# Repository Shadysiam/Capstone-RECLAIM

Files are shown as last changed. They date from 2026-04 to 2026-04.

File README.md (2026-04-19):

# RECLAIM — Autonomous Waste Collection & Sorting Robot

> **MSE 4499 Engineering Capstone — Western University, 2025–2026**
> **🏆 3rd Place at Capstone Showcase, March 26, 2026**

RECLAIM is an autonomous indoor robot designed to navigate post-event venues, detect waste on the ground using computer vision and depth sensing, pick it up with a 6-DOF robotic arm, classify it (recyclable / compost / landfill), and deposit it in the correct bin — fully autonomously.

---

## Demo

| | |
|---|---|
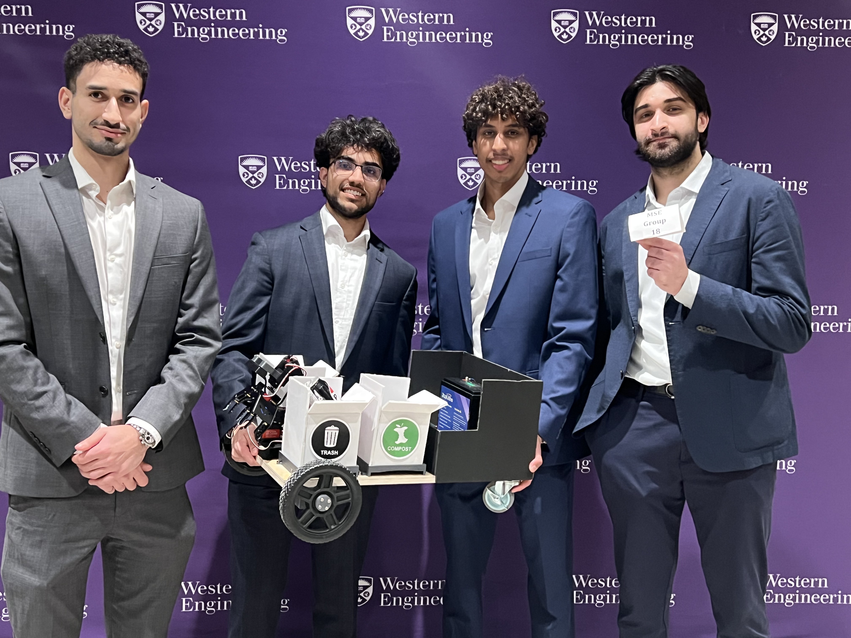
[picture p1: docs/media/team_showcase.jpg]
Team at Showcase
|  | **Western Engineering Capstone Showcase — March 26, 2026** <br><br> Team RECLAIM with the robot at the showcase. The arm, differential drive base, and sorting bins (Trash / Compost) are visible. <br><br> 🏆 **3rd Place overall** |

### Robot in Action

*Click any thumbnail to watch*

| | | |
|---|---|---|
| Demo 1 (https://youtube.com/shorts/9OcipLxrr-4) | Demo 2 (https://youtube.com/shorts/SzoJCjD1EAE) | Demo 3 (https://youtube.com/shorts/PJnd1PVIbLY) |

---

## System Overview

```
                          RECLAIM Robot

  ┌─────────────┐   ┌─────────────┐   ┌───────────────────────┐
  │ RPLIDAR A1  │   │  OAK-D Lite │   │   Jetson Orin NX      │
  │   LiDAR     │──▶│   Camera    │──▶│   MIC-711 / ROS2      │
  └─────────────┘   └─────────────┘   └───────────┬───────────┘
                                                   │
                                        ┌──────────▼──────────┐
                                        │     Teensy 4.1      │
                                        │     micro-ROS       │
                                        └──┬────────┬──────┬──┘
                                           │        │      │
             ┌─────────────────────────────┘        │      └─────────────────────┐
             │                                      │                            │
 ┌───────────▼──────────┐             ┌─────────────▼──────────┐  ┌─────────────▼──────────┐
 │  MD13C R3 (Left)     │             │   BTS7960 (Right)      │  │   6-DOF Servo Arm      │
 │  Motor Driver        │             │   Motor Driver         │  │   DS3218/DS3235/MG996R │
 └───────────┬──────────┘             └─────────────┬──────────┘  │   MoveIt2 Planning     │
             │                                      │             └────────────────────────┘
 ┌───────────▼──────────┐             ┌─────────────▼──────────┐
 │  JGB37-520 L Motor   │             │   JGB37-520 R Motor    │
 └──────────────────────┘             └────────────────────────┘
```

---

## Subsystems

### 🔋 Electrical & Power Distribution
- **Prototype:** 12.8V LiFePO4 battery → DC disconnect → 6-way fuse block → XINGYHENG buck converter (12V→6.8V servo bus) → Wago lever-nut distribution to 6 servo motors. 10,000µF bulk capacitance on servo rail.
- **Product PCB Design:** 24V input → dual-stage buck regulation (LM5116 24V→12V, TPS5430 12V→5V) → AMS1117 LDO (5V→3.3V) → E-stop relay circuit (G5LE-1A relay, IRLZ44N MOSFET gate driver, flyback diode protection) → fused distribution to all subsystems
- **KiCad Schematics:** Full hierarchical schematic design across 7 sheets (3 prototype + 4 product) with custom symbol libraries, netlist, and BOM documentation
- **Power Monitoring:** 3× INA226 current/power monitors on motor bus, compute rail, and servo rail

### 🚗 Locomotion & Motor Control
- **Differential drive** on two JGB37-520 12V motors with Hall-effect quadrature encoders
- **Mixed motor driver setup:** Cytron MD13C R3 (left) + BTS7960 (right), driven by Teensy 4.1 via PWM/DIR
- **PI velocity controller** on Teensy with per-wheel gains derived from step-response system identification
- Anti-windup, feedforward, low-pass filtering, ramp rate limiting (0.5 m/s²), static friction compensation
- **Calibrated odometry:** 1% distance error (50.5cm for 50cm target), 2-3° heading error on 360° spin
- Heading-hold controller in software bridge (Kp=2.0) to counteract castor drag

### 🗺️ Navigation & SLAM
- **SLAM Toolbox** for real-time mapping and localization using RPLIDAR A1M8
- **Nav2** autonomous navigation stack deployed on Jetson Orin NX via RoboStack/conda
- **`teensy_bridge.py`** ROS2 node: `/cmd_vel` → serial motor commands, encoder ticks → `/odom` publishing
- **Visual servoing pipeline** (`waste_tracker.py`): `SCAN → TURN_TO_TARGET → APPROACH → ALIGN` state machine
  - PID angular controller with Kalman filter (4-state: cx, cy, vx, vy) for smooth target tracking
  - EMA filtering, angular deadband, ramp limiting, coast-on-lost-detection
  - 5-frame detection confirmation before committing to a target
  - Speed proportional to distance: ramps from 0.12 to 0.04 m/s on approach

### 👁️ Perception
- **YOLOv8n** fine-tuned for waste classification (10-15 item classes → 3 bin categories)
- **OAK-D Lite** stereo depth camera via DepthAI v3 API — 640×480 @ 30.7 FPS
- Depth filtering (<1500mm), bbox area filtering (0.5–25% of frame), bottom-of-frame priority
- Detection published to `/perception/detections` as `DetectionArray` with 3D position

### 🦾 Robotic Arm
- 6-DOF arm with mixed servo types: DS3218 (270°, 21.5kg·cm), DS3235 (270°, 32kg·cm), MG996R
- LewanSoul mechanical claw gripper (0–193.5mm opening, 700g clamp force)
- Servo PWM controlled directly from Teensy 4.1 pins 10–15
- 6.8V servo bus with 10,000µF bulk capacitor to prevent brownout on simultaneous movement
- **MoveIt2** motion planning stack configured for the 6-DOF arm (`reclaim_arm_moveit_config`) — OMPL planner, joint limits, kinematics, and RViz visualization
- Full URDF model with STL meshes for each link — used for motion planning, collision checking, and Foxglove visualization

---

## Hardware

| Component | Model | Notes |
|---|---|---|
| Compute | Advantech MIC-711 (Jetson Orin NX) | ROS2 Humble via RoboStack/conda |
| Microcontroller | Teensy 4.1 | micro-ROS, USB serial @ 115200 baud |
| Camera | OAK-D Lite | DepthAI v3, USB 3.0, stereo depth |
| LiDAR | RPLIDAR A1M8 | 360°, 0.15–12m range |
| Drive Motors | 2× JGB37-520 12V 37RPM | Hall-effect quadrature encoders |
| Motor Drivers | Cytron MD13C R3 + BTS7960 | PWM+DIR / LPWM+RPWM |
| Arm Servos | DS3218, DS3235, MG996R | 6-DOF, mixed torque ratings |
| Battery | ZapLitho 12.8V 22Ah LiFePO4 | 30A BMS |
| Network | GL.iNet Mango router | WiFi bridge for SSH/rsync |

---

## Software Stack

| Layer | Technology |
|---|---|
| OS | Ubuntu 20.04 (JetPack 5.x) |
| Robot Framework | ROS2 Humble (via RoboStack/conda) |
| SLAM | SLAM Toolbox |
| Navigation | Nav2 |
| Firmware | PlatformIO / micro-ROS (Teensy 4.1) |
| Perception | YOLOv8n + DepthAI v3 |
| Visualization | Foxglove Studio |
| Schematic Design | KiCad 10 |

---

## Repository Structure

```
reclaim_ws/
├── src/
│   ├── reclaim_perception/       # OAK-D pipeline, YOLO inference, detection publisher
│   ├── reclaim_navigation/       # SLAM Toolbox, Nav2, LiDAR configs
│   ├── reclaim_control/          # Teensy firmware (PlatformIO) + micro-ROS
│   │   └── firmware/             # Motor control, encoder, servo firmware
│   ├── reclaim_bringup/          # State machine, system integration, top-level launch
│   └── reclaim_interfaces/       # Custom ROS2 msg/srv/action definitions
├── docs/
│   ├── product_pcb_electrical/   # Product KiCad schematic (4 sheets, STM32-based)
│   ├── prototype_pcb_electrical/ # Prototype KiCad schematic (3 sheets, Teensy-based)
│   ├── schematic_images/         # Exported PDFs + wiring guide
│   ├── Teensy.md                 # Pin map, flash procedure, serial comms
│   └── Perception_Strategy.md    # YOLO training strategy, OAK-D depth pipeline
├── matlab_sims/                  # Motor modelling, Bode plots, control tuning
├── sync.sh                       # rsync wrapper: edit locally → deploy to MIC-711
└── setup.sh                      # Environment setup script
```

---

## Quick Start (on MIC-711)

```bash
# Activate ROS2 environment
conda activate ros_env

# Sync from Mac (run on Mac)
./sync.sh reclaim_control --build

# Launch full system
source install/setup.bash
ros2 launch reclaim_bringup full_system.launch.py
```

---

## My Contributions (Shady Siam)

- **Electrical system design** — full power distribution for prototype and product PCB, including multi-stage buck regulation, E-stop relay circuit, servo bus design, and component selection
- **KiCad schematics** — 7-sheet hierarchical schematic design (product + prototype) with custom symbol libraries
- **Motor control firmware** — PI velocity controller on Teensy 4.1 with system identification, odometry calibration, and heading hold
- **ROS2 navigation stack** — SLAM Toolbox, Nav2, odometry bridge, visual servoing pipeline with Kalman-filtered target tracking
- **Systems integration** — full software environment setup on Jetson Orin NX, SSH/rsync workflow, Foxglove visualization

---

## Team

| Name | Role |
|---|---|
| Shady Siam | Electrical systems, power distribution, locomotion, navigation & SLAM |
| Issa Ahmed | AI stack, perception (YOLOv8n), autonomous operation |
| Dev Panara | Robotic arm, mechanical design, CAD |
| Abdul Kassem | Product locomotion (motor selection, torque analysis), commercialization strategy |

---

*Western University — MSE 4499 Engineering Capstone, 2025–2026*

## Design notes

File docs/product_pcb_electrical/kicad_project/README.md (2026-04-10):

# RECLAIM PCB — KiCad Project

## Files in This Directory

| File | Purpose |
|---|---|
| `RECLAIM_PCB/RECLAIM_PCB.kicad_pro` | KiCad project file (design rules, net classes, layer stack) |
| `RECLAIM_PCB/RECLAIM_PCB.kicad_sch` | Main schematic (all 9 sections, annotated) |
| `RECLAIM_PCB/fp-lib-table` | Footprint library table (maps to KiCad 7 standard libs) |
| `RECLAIM_PCB/sym-lib-table` | Symbol library table |
| `../bom.csv` | Complete BOM with MPN, footprint, value for every component |
| `../netlist.md` | Human-readable netlist — every pin-to-net connection |
| `../block_diagram.md` | System block diagrams (power + signal architecture) |
| `../component_justification.md` | Why each component was selected |

## How to Open in KiCad 7

1. Open KiCad 7 application
2. **File → Open Project** → select `RECLAIM_PCB/RECLAIM_PCB.kicad_pro`
3. In the KiCad project manager, open the schematic editor (`.kicad_sch`)

## How to Open in Flux (flux.ai)

1. Go to flux.ai → New Project
2. Import BOM: **File → Import → CSV BOM** → select `../bom.csv`
3. For the schematic, use `netlist.md` as a reference to draw connections

## Schematic Entry Order (recommended)

Start with the sections as they appear in `block_diagram.md`:

1. **Section 1 — Power Input & Distribution** ← START HERE
   - J_BATTERY, SW1, F1, K1, F2-F4
   - U1 (TPS5430 25V→12V), U2 (TPS5430 12V→5V), U3 (AMS1117 5V→3.3V)
   - Bulk caps C1-C4, decoupling C5-C8, buck inductors, freewheeling diodes

2. **Section 8 — E-Stop** ← Draw with Section 1 (shares relay K1)
   - Q1 (IRLZ44N), D2 (1N4007), R11 (1k gate resistor)
   - Bumper switch connectors J_BUMPER_FL/FR/RL/RR

3. **Section 2 — STM32F405 MCU**
   - U4 (STM32F405RGT6 LQFP-64)
   - Crystal Y1 + load caps C9/C10
   - Pull-up R1 (NRST), pull-down R2 (BOOT0)
   - SWD header J2, USB-C J3, CP2102N U_USB

4. **Section 3 — Motor Drivers**
   - U5L/U5R (DRV8243) × 2 identical sections
   - Sense resistors R3L/R3R, TVS diodes TVS1L/TVS1R
   - Motor output connectors J_MOTOR_L/R, encoder connectors J_ENC_L/R

5. **Section 4 — CAN Bus**
   - U6A/U6S (SN65HVD230) × 2
   - Termination R4A/R4S (120Ω)
   - CAN arm connector J_CAN_ARM

6. **Section 5 — IMU**
   - U7 (ICM-42688-P LGA-14)
   - Decoupling C15/C16

7. **Section 6 — Power Monitoring**
   - U8/U9/U10 (INA226) × 3
   - Shunt resistors R6/R7/R8 (10mΩ)
   - I2C address config via A0/A1 pins

8. **Section 7 — LED & Work Light**
   - WS2812B connector J_LED_STATUS, series R9, bulk C20
   - PT4115 U11, inductor L1, freewheeling D1, set resistor R10
   - Work light connector J_LED_WORK

## STM32F405 LQFP-64 Pin Assignment Quick Reference

Full table in `netlist.md`. Key assignments:
- PA2/PA3: USART2 TX/RX → Jetson micro-ROS
- PA5/6/7: SPI1 SCK/MISO/MOSI
- PA8/PA9: TIM1 encoder Left
- PB0/PB1/PB2: SPI CS for DRV_L, DRV_R, ICM
- PB4/PB5: TIM3 encoder Right
- PB6/PB7: I2C1 SCL/SDA → INA226×3
- PB8/PB9: CAN1 Arm bus
- PB12/PB13: CAN2 Spare
- PC6/PC7: TIM8 WS2812B / PT4115 PWM
- PC8: E-stop relay control
- PC9-PC12: Bumper switches

## Net Classes (already configured in .kicad_pro)

| Net Class | Track Width | Used For |
|---|---|---|
| Battery_Main | 6mm | VBAT, GND battery return |
| Power_25V_Motor | 4mm | VCC_25V, MOTOR_PWR_L/R |
| Power_5V_12V | 2mm | VCC_12V, VCC_5V |
| Default (3.3V + signal) | 0.25mm | VCC_3V3, all signals |
| CAN_Differential | 0.2mm | CAN_H/CAN_L pairs |

## PCB Layer Stack

```
Layer 1 (Top):     Signal + SMD components
Layer 2 (Inner 1): Ground plane — SOLID pour, no splits
Layer 3 (Inner 2): Power planes — split zones: 25V | 12V | 5V
Layer 4 (Bottom):  Signal + THT components + connectors
```

## DRC Rules Summary

- Min trace: 0.2mm signal / 2mm 5V-12V / 4mm 25V-motor / 6mm battery
- Min clearance: 0.2mm signal-to-signal / 0.5mm power-to-signal
- Via: 0.6mm drill / 1.0mm pad (signal) — 1.2mm drill / 2.0mm pad (power)
- Thermal relief: required on all power plane connections
- IMU: dedicated ground island, single via stitch
- Crystal: no traces underneath, ground guard ring
- CAN pairs: matched length to within 0.5mm, 120Ω differential impedance

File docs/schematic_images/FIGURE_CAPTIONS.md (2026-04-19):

# IEEE Figure Captions — Design Documentation

Copy-paste these into the report. Number sequentially within each section.

---

## Prototype Schematics

**Fig. X.** Prototype power distribution schematic. LiFePO4 12.8 V 22 Ah battery feeds a DPST DC switch, 6-way fuse block (30 A, 5 A, 5 A, 2 A), and XINGYHENG 20 A buck converter (6.8 V output) supplying servo bus via Wago 221-415 lever-nut connectors.
`Prototype_Power_Distribution.pdf`

**Fig. X.** Prototype Teensy 4.1 motor-control schematic. Cytron MD13C R3 (left motor) and BTS7960 (right motor) H-bridge drivers interface with Teensy 4.1 via PWM/DIR signals. Six servo PWM outputs (J1–J6) and two quadrature encoder inputs (left/right) are routed through net labels.
`Prototype_Teensy_Motor_Control.pdf`

**Fig. X.** Prototype peripheral and sensor connections. Advantech MIC-711 (Jetson Orin NX) connects via Ethernet (GL.iNet router), USB 3.0 (OAK-D Lite stereo camera), and USB 2.0 (RPLIDAR A1M8, Teensy 4.1).
`Prototype_Peripherals_Sensors.pdf`

---

## Product Schematics

**Fig. X.** Product power distribution and E-stop schematic. 25.6 V 100 Ah LiFePO4 battery, DC push-switch, fuse block (30 A main, 5 A, 2 A), relay-based E-stop circuit with flyback diode, LM51652 buck controller (12 V output), and post-regulation LDO (3.3 V). Total budget: 2,560 Wh.
`Product_Power_Distribution.pdf`

**Fig. X.** Product STM32F405RGT6 MCU schematic. 8 MHz crystal oscillator (C8/C10 load caps), SPI bus (SCK, MOSI, MISO) with chip-select lines for DRV8243 and IMU, dual CAN bus (CAN1/CAN2), USART2, I2C1 (4.7 k pull-ups), and quadrature encoder inputs (ENC_L_A/B, ENC_R_A/B).
`Product_STM32_MCU.pdf`

**Fig. X.** Product motor driver, CAN transceiver, and IMU schematic. Dual DRV8243-Q1 smart half-bridge gate drivers, CAN transceiver, 6-axis IMU, and associated decoupling capacitor network. Fault and enable lines routed to STM32 GPIO via net labels.
`Product_Drivers_CAN_IMU_Power.pdf`

**Fig. X.** Product connector, LED indicator, and USB schematic. Board-edge connectors for motors, encoders, servos, and external sensors. Status LEDs, USB Type-C connector for programming/debug, and UART debug header.
`Product_Connectors_LED_USB.pdf`

---

## Simulink / Control System Figures

**Fig. X.** Simulink block diagram of the prototype PI closed-loop velocity controller. The discrete-time loop operates at 50 Hz on the Teensy 4.1 with gains K_p = 940 and K_i = 38,230, PWM saturation (−255 to 255), and a first-order DC motor plant model (JGB37-520). Encoder feedback provides 7,560 ticks/rev odometry.
`Simulink_Prototype_Controls.png`

**Fig. X.** PI velocity controller step and ramp response. (Left) Step response at 0.20 m/s showing 52 ms rise time and 176 ms settling time for the closed-loop system versus open-loop PWM. (Center) Approach speed comparison at 0.12 m/s and 0.20 m/s setpoints. (Right) Ramp limiter effect at 0.3 m/s^2 limiting acceleration to prevent wheel slip.
`Simulink_Motor_Response_Prototype.jpg`

**Fig. X.** Closed-loop frequency response (Bode magnitude plot) of the PI-controlled drive system. The −3 dB bandwidth is 6.2 Hz, confirming adequate disturbance rejection for indoor navigation at speeds up to 0.20 m/s.
`Simulink_Bode_Plot.png`

---

## Notes

- Replace "Fig. X." with the actual figure number in context (e.g., Fig. 8.3.1).
- All schematics are vector PDFs — scale without quality loss.
- Simulink images are raster PNG/JPG — embed at native resolution.

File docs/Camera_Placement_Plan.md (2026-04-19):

# Camera Placement Plan — RECLAIM

> Decisions and specs for mounting the OAK-D Lite on the robot. Read this before designing the mount in CAD.

## Decision: Front Base Plate Mount (Eye-to-Hand)

Mount the OAK-D Lite on the front face of the arm base plate, below J1. The camera is fixed to the robot chassis (not the arm itself), so it does not move when the arm moves.

**Why eye-to-hand over eye-in-hand:**
- Simpler calibration (one static transform instead of a moving kinematic chain)
- Camera only needs a clear view before the arm moves
- Less wiring complexity, no cable routing through rotating joints

**Workflow:**
1. Robot drives toward waste, stops ~50cm away
2. Camera captures scene while arm is in home position (clear FOV)
3. YOLO detects waste, stereo depth gives 3D coordinates
4. Coordinates transformed from camera frame to arm base frame via static TF
5. Arm moves to pick. Camera view is occluded by the arm during pickup, but we already have the coordinates we need.

## Camera Selection

**OAK-D Lite, Auto-Focus version recommended.**

Reason: Objects will be at 30-50cm from the camera during pickup. Auto-focus handles close-range better. Fixed-focus is optimized for 50cm+ and vibrating platforms (not our use case).

## Depth Range Constraint

From Luxonis documentation (OAK-D Lite, 480P extended disparity):

| Range | Accuracy | Notes |
|---|---|---|
| 20-40cm | Works but >2% error | Absolute minimum depth range |
| **40cm - 3m** | **Sub-2% error** | **Ideal operating range** |
| >3m | Increasing error | Not relevant for pickup |

**This means the camera-to-waste distance should be >= 40cm for reliable depth.** Mounting low on the base plate may put objects at only ~30cm, which is below ideal. Two options:

### Option A: Low Mount (Base Plate)
- Camera at ~15cm above ground
- Object on ground at ~30cm from camera
- Marginal depth accuracy, but may be acceptable for pickup (we only need ~2cm precision for gripper alignment)
- Simplest mechanically

### Option B: Tower Mount (Behind Arm)
- Camera on a vertical post behind the arm, ~40cm above ground
- Tilted ~45 degrees downward
- Object on ground at ~47cm from camera (within ideal range)
- Better depth accuracy
- More complex mechanically, adds height to robot

**Current plan: Try Option A first.** Test depth accuracy at 30cm using `camera_detect.py`. If depth error is too large for reliable pickup, switch to Option B.

## OAK-D Lite Mounting Hardware

- **Back panel:** 2x M4 screw holes, 75mm VESA spacing (center-to-center)
- **Bottom:** 1x 1/4-20 UNC tripod mount
- **Camera dimensions:** ~91 x 28 x 17.5mm
- **Stereo baseline:** 7.5cm

For the base plate mount, the 1/4-20 tripod mount on the bottom is probably easiest. A simple L-bracket with a 1/4-20 bolt would work.

## Camera Intrinsics (for depth-to-3D conversion)

OAK-D Lite specs:
- RGB: 4208x3120, 81 DFOV
- Stereo: 640x480, 73 HFOV, 58 VFOV (per mono camera)
- Combined: ~69 HFOV, ~54 VFOV for depth

Exact intrinsics (fx, fy, cx, cy) are device-specific and read at runtime from the camera's EEPROM via DepthAI API.

## Static Transform: Camera to J1

This transform needs to be measured after the mount is built and the arm is assembled in CAD.

```
# Transform chain
map -> odom -> base_link -> camera_link -> camera_optical_frame

# The static TF we need to define:
base_link -> camera_link
```

**To measure:** Once the mount is CAD'd, extract the (x, y, z) offset and (roll, pitch, yaw) rotation from the camera optical center to the J1 rotation axis. This goes into a static transform publisher in the launch file.

## CAD Tasks

1. **Design camera mount bracket** — L-bracket or plate that attaches to arm base plate, holds OAK-D Lite via 1/4-20 bolt or M4 screws
2. **Model OAK-D Lite** — Use dimensions from Luxonis (91 x 28 x 17.5mm, 7.5cm baseline, mounting holes)
3. **Integrate into full arm assembly CAD** — Position camera mount on base plate, verify no collision with arm in home position and during pickup sequence
4. **Extract camera-to-J1 transform** — Measure offset from CAD for the static TF
5. **Verify FOV clearance** — Ensure the camera's 69x54 degree FOV covers the ground area in front of the robot at the expected pickup distance

## Open Questions

- Exact chassis height (depends on final frame design with 7" wheels)
- Whether 30cm depth accuracy is good enough (test empirically)
- Camera tilt angle (0 degrees = horizontal, need slight downward tilt to see ground)
- Cable routing from camera to MIC-711 (USB3 cable, max ~3m)

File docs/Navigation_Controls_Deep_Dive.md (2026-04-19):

# RECLAIM Navigation & Controls — Deep Dive

## How Every Constant Was Determined

### Wheel Radius: 0.05232m

**Method**: Iterative calibration. Command the robot to drive forward 50cm (using encoder counts). Measure actual distance with tape measure.

```
expected_distance = (ticks / 7560) * 2pi * r
```

If the robot drove 54.5cm when we expected 50cm, the radius is too big. Adjust:
```
r_new = r_old * (expected / actual) = 0.048 * (50 / 54.5) = 0.04404
```

Iterated 5 times until forward and reverse distance matched within ~1cm over 50cm. Final value: **0.05232m**.

### Wheel Separation: 0.470m

**Method**: 360 degree spin test. Command the robot to spin in place for exactly one full rotation (using encoder-based yaw). Measure the actual rotation.

```
yaw_per_tick = (2pi * wheel_radius) / (ticks_per_rev * wheel_separation)
```

If the robot overshot 360 by 18 degrees with wheel_sep = 0.494, the separation is too large:
```
sep_new = sep_old * (actual_rotation / expected_rotation) = 0.494 * (378 / 360) = 0.470
```

### Ticks Per Rev: 7560

**Method**: Hardware spec confirmed by measurement. JGB37-520 has:
- 7 PPR (pulses per revolution) base encoder
- 270:1 gearbox
- Quadrature decoding (x4)
```
7 * 270 * 4 = 7560 ticks per output shaft revolution
```

Verified by marking the wheel, spinning one full revolution by hand, and reading TICKS from serial.

### P Gain (Kp = 0.003 turn, 0.002 approach)

**Method**: Empirical tuning starting from theoretical estimate.

Relationship: `angular_velocity = Kp * pixel_offset`

Image is 640px wide, so max offset from center is 320px.

At Kp = 0.003: `max_w = 0.003 * 320 = 0.96 rad/s` (capped at 0.20)

Tuning logic:
- Too high -> oscillation (overshoots center, corrects back, overshoots again)
- Too low -> sluggish (takes many seconds to center, target might move)
- 0.003 produces 0.30 rad/s at 100px offset -- aggressive enough to center in ~1s
- 0.002 for approach because at 0.25 m/s forward speed, fast angular corrections cause visible swerving

### Motor Deadband: 0.04 rad/s

**Method**: Observation. Send decreasing angular velocities and watch when the motors stop responding. Below ~0.04 rad/s, the wheel speed commands translate to PWM values too low to overcome stiction in the motor + gearbox. Hardware limitation of the JGB37-520 with 270:1 reduction.

### EMA Alpha: 0.5

**Method**: Tradeoff analysis between responsiveness and smoothness.

```
alpha = 0.5:  50% raw, 50% previous   -> settles in ~3 frames (100ms)
alpha = 0.3:  30% raw, 70% previous   -> settles in ~6 frames (200ms)
alpha = 0.8:  80% raw, 20% previous   -> settles in ~1 frame (barely filters)
```

At 30fps, raw data has ~8px noise. Alpha 0.5 cuts noise in half without noticeable lag. 0.3 was too sluggish, 0.8 barely filtered.

### Heading Hold Kp: 2.0

**Method**: Straight-line driving test (2m).

- Kp = 1.0: corrects slowly, robot drifts ~5cm over 2m
- Kp = 2.0: snaps back within ~200ms, drift < 1cm over 2m
- Kp = 4.0: overcorrects, visible wobble

### Scan Speed: 0.3 rad/s

Full 360 takes `6.28 / 0.3 = ~21 seconds`. At 30fps, camera captures ~3 frames per degree of rotation.

### Approach Max Speed: 0.25 m/s

Motors' no-load speed is 37 RPM:
```
max_wheel_speed = 0.05232 * 2pi * 37/60 = 0.203 m/s
```

0.25 m/s is achievable during straight driving where both wheels share load.

### Stop Distance: 200mm (base_x)

Arm's working range: gripper reaches approximately 150-250mm from J1 base joint. 200mm puts the object in the middle of reachable zone.

### S-curve Ramp: 1.5 seconds

Cosine ramp has zero acceleration at start and end (no jerk):

```
v(t) = v_target * 0.5 * (1 - cos(pi * t / 1.5))
a(t) = v_target * pi/(2*1.5) * sin(pi * t / 1.5)
```

At t=0: a = 0 (no jerk). At t=0.75s: a = max. At t=1.5s: a = 0 (smooth).

### Max Acceleration: 0.3 m/s^2

Prevents wheel slip on smooth floors. Going from 0 to 0.20 m/s in one tick (33ms) would require 6 m/s^2 -- wheels slip on tile. At 0.3 m/s^2, takes ~0.67s.

### Confidence Threshold: 0.50

YOLO standard. 0.30 catches more but also picks up shadows/stains. 0.70 misses partially occluded objects.

### Confirm Threshold: 3 frames

At 20Hz, 3 frames = 150ms. Real objects persist for hundreds of frames. Noise rarely lasts >1-2 frames.

---

## The Full Control Hierarchy

### Layer 1: Teensy Firmware (Lowest Level)

Receives `SETVEL 0.108 0.132` over USB serial. Runs PI controller on each wheel:

```
error = target_velocity - measured_velocity
PWM += Kp * error + Ki * integral(error)
```

Measured velocity from encoders: 7560 ticks/rev, sampled at ~100Hz.
```
velocity = (ticks_per_sec / 7560) * 2pi * 0.05232
```

### Layer 2: Teensy Bridge (Middle Level)

ROS2 node on MIC-711. Four responsibilities:

**a) Velocity conversion** -- differential drive inverse kinematics:
```
v_left  = v - w * 0.235
v_right = v + w * 0.235
```

**b) Heading hold** -- locks heading when driving straight:
```python
if abs(v) > 0.005 and abs(w) < 0.02:
    heading_error = target_heading - actual_heading
    w = 2.0 * heading_error
```

**c) Ramp limiter** -- caps acceleration at 0.3 m/s^2

**d) Odometry** -- dead reckoning from encoder ticks at 10Hz:
```
delta_distance = (delta_left + delta_right) / 2
delta_theta    = (delta_right - delta_left) / 0.470
x += delta_distance * cos(theta)
y += delta_distance * sin(theta)
```

### Layer 3: Waste Tracker (Top Level -- The Brain)

State machine with visual servoing:

**SCAN**: Rotate at 0.3 rad/s. Confirm detections over 3 frames. Lock on nearest.

**TURN_TO_TARGET**: P controller centers target in camera frame.
```
pixel_offset = target_cx - 320
angular_vel = -0.003 * pixel_offset
```

**APPROACH**: Drive forward (speed proportional to distance) while steering to keep centered.
```
v = 0.04 + (0.25 - 0.04) * dist_ratio
w = -0.002 * pixel_offset
```

**ALIGN**: Final precise centering. 5 stable frames within 30px of center.

### The 4-Stage Smoothing Pipeline

```
Raw bbox -> Bbox EMA (alpha=0.5) -> P controller -> Angular EMA (alpha=0.45) -> Deadband taper -> Sinusoidal ramp -> cmd_vel
```

---

## Knowledge Test

### Phase 1: Fundamentals

1. Robot needs v=0.15 m/s, w=0.10 rad/s. What are left/right wheel velocities?
   **Answer**: v_left = 0.15 - 0.10*0.235 = 0.1265 m/s, v_right = 0.15 + 0.10*0.235 = 0.1735 m/s

2. Left encoder reads 3780 more ticks, right reads 3780. How far? Turn?
   **Answer**: Distance = (3780/7560) * 2pi * 0.05232 = 0.1645m. No turn -- both equal.

3. Target 80px right of center, Kp=0.003. Angular velocity? Direction?
   **Answer**: w = -0.003 * 80 = -0.24 rad/s. Turns right (clockwise, negative).

4. EMA alpha=0.5, current=0.10 rad/s, new raw=0.20 rad/s. New filtered?
   **Answer**: 0.5 * 0.20 + 0.5 * 0.10 = 0.15 rad/s

### Phase 2: State Machine Logic

5. SCAN: cup detected 2 frames, lost 1 frame, detected again. Lock on?
   **Answer**: No -- confirm resets on loss (no gap tolerance in friend's version).

6. APPROACH, cam_z=700mm. Forward speed? (before ramp)
   **Answer**: dist_ratio = (700-250)/1100 = 0.409. v = 0.04 + 0.21*0.409 = 0.126 m/s

7. APPROACH, target lost, cam_z was 400mm. What happens?
   **Answer**: Lost at close range (<500mm) for 50 frames -> IDLE. Probably at target.

8. TURN, detection 250px from last known. Returned by _find_target_in_detections?
   **Answer**: Yes -- during TURN, max_radius = 300px. 250 < 300.

### Phase 3: Smoothing & Controls

9. Why is Ki harmful if target disappears for 20 frames?
   **Answer**: Integral winds up during loss (error stays large). When target reappears, accumulated integral causes huge overshoot.

10. t=0.5s into approach (ramp_time=1.5s). Fraction of full speed?
    **Answer**: ramp = 0.5*(1-cos(pi*0.5/1.5)) = 0.5*(1-cos(60deg)) = 0.5*0.5 = 0.25 (25%)

11. P controller outputs 0.02 rad/s. What gets sent to motors?
    **Answer**: 0.02 < 0.04 deadband, overridden to 0.04 rad/s.

12. Driving straight at 0.12 m/s, heading drifts 0.05 rad. Heading hold output?
    **Answer**: w = 2.0 * 0.05 = 0.10 rad/s corrective rotation.

### Phase 4: System Integration

13. TRT server down for 3s during APPROACH?
    **Answer**: latest_detections stays empty. target_lost_count hits 50 (2.5s). Decides based on last depth.

14. Why Connection: close on HTTP requests?
    **Answer**: Prevents stale keep-alive state. Each request is fresh.

15. Tracker crashes but bridge keeps running?
    **Answer**: cmd_vel timeout fires after 0.5s. Motors stop safely.

16. Wheel radius wrong by 10% -- what breaks?
    **Answer**: Odometry position is off, but yaw uses ratio of left/right so mostly unaffected. Approach stop uses cam_z not odometry so still fine. Main break is distance estimation.

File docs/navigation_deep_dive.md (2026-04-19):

# RECLAIM — Navigation & Controls Deep Dive

## How Every Constant Was Determined

### Wheel Radius: 0.05232m

**How we got it**: Iterative calibration. Command the robot to drive forward 50cm (using encoder counts). Measure the actual distance with a tape measure.

```
expected_distance = (ticks / 7560) * 2pi * r
```

If the robot drove 54.5cm when we expected 50cm, the radius is too big. Adjust:
```
r_new = r_old * (expected / actual) = 0.048 * (50 / 54.5) = 0.04404
```

This was iterated 5 times until forward and reverse distance matched within ~1cm over 50cm. Final value: **0.05232m**.

### Wheel Separation: 0.470m

**How we got it**: 360 spin test. Command the robot to spin in place for exactly one full rotation (using encoder-based yaw). Measure the actual rotation.

```
yaw_per_tick = (2pi * wheel_radius) / (ticks_per_rev * wheel_separation)
```

If the robot overshot 360 by 18 degrees with `wheel_sep = 0.494`, the separation is too large. The wheels are closer than we thought, so each tick produces more rotation than expected:
```
sep_new = sep_old * (actual_rotation / expected_rotation) = 0.494 * (378 / 360) = 0.470
```

### Ticks Per Rev: 7560

**How we got it**: Hardware spec confirmed by measurement. The JGB37-520 has:
- 7 PPR (pulses per revolution) base encoder
- 270:1 gearbox
- Quadrature decoding (x4)
```
7 * 270 * 4 = 7560 ticks per output shaft revolution
```

Verified by marking the wheel, spinning one full revolution by hand, and reading TICKS from serial.

### P Gain (Kp = 0.003 turn, 0.002 approach)

**How it was tuned**: Start with a guess, then adjust empirically.

The relationship is: `angular_velocity = Kp * pixel_offset`

Image is 640px wide, so max offset from center is 320px.

At Kp = 0.003: `max_w = 0.003 * 320 = 0.96 rad/s` (capped at 0.20)

The thought process:
- Too high: oscillation (overshoots center, corrects back, overshoots again)
- Too low: sluggish (takes many seconds to center, target might move)
- 0.003 produces 0.30 rad/s at 100px offset — aggressive enough to center in ~1s
- 0.002 for approach because at 0.25 m/s forward speed, fast angular corrections cause visible swerving

### Motor Deadband: 0.04 rad/s

**How we got it**: Observation. Send decreasing angular velocities and watch when the motors stop responding. Below ~0.04 rad/s, the wheel speed commands translate to PWM values too low to overcome stiction in the motor + gearbox. This is a **hardware limitation** of the JGB37-520 with 270:1 reduction — the gearbox has high stiction at low speeds.

### EMA Alpha: 0.5

**How we chose it**: Tradeoff between responsiveness and smoothness.

```
alpha = 0.5:  50% raw, 50% previous   -> settles in ~3 frames (100ms)
alpha = 0.3:  30% raw, 70% previous   -> settles in ~6 frames (200ms)
alpha = 0.8:  80% raw, 20% previous   -> settles in ~1 frame (barely filters)
```

At 30fps, the raw data is already fairly clean (~8px noise). Alpha 0.5 cuts the noise in half without adding noticeable lag. Chosen by testing — 0.3 was too sluggish (robot couldn't track a moving target), 0.8 was barely different from raw.

### Heading Hold Kp: 2.0

**How it was tuned**: Drive the robot straight for 2m. Watch if it drifts.

- Kp = 1.0: corrects slowly, robot drifts ~5cm over 2m
- Kp = 2.0: snaps back within ~200ms, drift < 1cm over 2m
- Kp = 4.0: overcorrects, visible wobble

2.0 is the sweet spot — strong enough to counteract castor drag immediately, not so strong it oscillates.

### Scan Speed: 0.3 rad/s

**How it was chosen**: Full 360 takes `6.28 / 0.3 = ~21 seconds`. This gives the camera enough time to see objects at each angle — at 30fps, the camera captures ~3 frames per degree of rotation. Too fast and you miss objects. Too slow and the scan takes forever.

### Approach Max Speed: 0.25 m/s

**Why this value**: The motors' no-load speed is 37 RPM:
```
max_wheel_speed = 0.05232 * 2pi * 37/60 = 0.203 m/s
```

At 0.25 m/s, one wheel (during a turn) would need to go faster than this — so the actual achievable straight-line speed is slightly above 0.20. 0.25 is aggressive but achievable because during straight driving both wheels share the load.

### Stop Distance: 200mm (base_x)

**Why**: This is the arm's working range. The gripper can reach approximately 150-250mm from the J1 base joint. Stopping at 200mm puts the object right in the middle of the arm's reachable zone. This is measured from the camera-to-base_link transform, not raw camera depth.

### S-curve Ramp: 1.5 seconds

**Why cosine, why 1.5s**:

Linear ramp (v increases at constant rate) has **discontinuous acceleration** — at t=0 acceleration jumps from 0 to some value, causing a jerk. Cosine ramp has **zero acceleration at start and end**:

```
v(t) = v_target * 0.5 * (1 - cos(pi * t / 1.5))
a(t) = v_target * pi/(2*1.5) * sin(pi * t / 1.5)
```

At t=0: `a = 0` (no jerk). At t=0.75s: `a = max` (peak acceleration). At t=1.5s: `a = 0` (smooth arrival at target speed).

1.5s was chosen to balance smoothness vs responsiveness. At 0.20 m/s, 1.5s means the robot covers ~15cm during ramp-up. Too long and the robot seems sluggish. Too short and you still get a jolt.

### Max Acceleration: 0.3 m/s^2

**Why**: At the bridge level, this prevents wheel slip on smooth floors. Going from 0 to 0.20 m/s in one tick (33ms) would require 6 m/s^2 — the wheels would slip on tile/laminate floors. At 0.3 m/s^2, it takes ~0.67s to reach full speed — smooth and grippy.

### Confidence Threshold: 0.50

**Why**: YOLO outputs a confidence score 0-1. At 0.50, roughly half of real trash is detected with very few false positives. Lower (0.30) catches more trash but also picks up floor stains, shadows. Higher (0.70) misses partially occluded objects. 0.50 is the standard YOLO threshold.

### Confirm Threshold: 3 frames

**Why**: At 20Hz polling, 3 frames = 150ms. A real object will persist for hundreds of frames. Noise/reflections rarely last more than 1-2 frames. 3 is the minimum that reliably filters flicker without adding noticeable delay (you don't want the robot to rotate past the object waiting for confirmation).

---

## The Full System Architecture

### The Physical System

Differential drive robot — two powered wheels with encoders, two passive castors. The left and right motors are independently controlled:

- **Both wheels same speed** -> drives straight
- **Right faster than left** -> arcs left
- **Wheels opposite directions** -> spins in place

The fundamental equation (inverse kinematics):
```
v_left  = v - w * 0.235
v_right = v + w * 0.235
```

The `0.235` is half the wheel separation (0.470m / 2).

### The Control Hierarchy (Bottom to Top)

```
Layer 3:  WHAT to do     waste_tracker_trt.py    "see trash, drive to it"
Layer 2:  HOW to move    teensy_bridge.py        "v=0.12, w=0.05 -> left/right wheel speeds"
Layer 1:  MAKE it move   Teensy firmware          "target velocity -> PWM via PI loop"
```

#### Layer 1: Teensy (Lowest Level)

The Teensy receives `SETVEL 0.108 0.132` over USB serial. It runs a **PI controller** on each wheel:

```
error = target_velocity - measured_velocity
PWM += Kp * error + Ki * integral(error)
```

The measured velocity comes from the encoders. 7560 ticks per wheel revolution, sampled at ~100Hz on the Teensy. It converts ticks/sec to m/s using:

```
velocity = (ticks_per_sec / 7560) * 2pi * 0.05232
```

This is a **closed-loop velocity controller** — it adjusts PWM to match the target speed regardless of battery voltage, floor friction, or load.

#### Layer 2: Teensy Bridge (Middle Level)

ROS2 node on the MIC-711. Does three things:

**a) Velocity conversion** — takes `/cmd_vel` (Twist message with v and w) and converts to left/right wheel velocities using the diff drive equation.

**b) Heading hold** — when the tracker says "drive straight" (`w ~ 0`), the bridge:
1. Records the current heading from odometry
2. Every tick, measures the actual heading
3. If the robot drifts, computes: `w_correction = 2.0 * (target_heading - actual_heading)`
4. Adds this correction to the wheel commands

Even though the tracker says "go straight," the bridge actively fights castor drift.

**c) Odometry** — polls encoder ticks at 10Hz, computes position:
```
delta_left  = (delta_ticks_L / 7560) * 2pi * 0.05232   # meters left wheel
delta_right = (delta_ticks_R / 7560) * 2pi * 0.05232   # meters right wheel
delta_distance = (delta_left + delta_right) / 2          # center displacement
delta_theta    = (delta_right - delta_left) / 0.470      # heading change
x += delta_distance * cos(theta)
y += delta_distance * sin(theta)
theta += delta_theta
```

This is **dead reckoning** — accumulates position from wheel movements. Drifts over time but accurate enough for scan completion and heading hold.

**d) Ramp limiter** — caps acceleration at 0.3 m/s^2. Prevents jerky starts.

#### Layer 3: Waste Tracker (Top Level — The Brain)

Finite state machine with visual servoing.

---

## The State Machine In Detail

### State 1: SCAN

**Purpose**: Find waste on the ground by rotating in place.

**How it works**:
1. Commands `w = 0.3 rad/s` (CCW rotation, ~21 seconds for 360 degrees)
2. Every tick, reads yaw from odometry to track rotation progress
3. TRT poll thread gets detections in parallel
4. Each tick checks: "did I see anything?"

**Scan accumulation hack**: Castors scrub during rotation causing brief backward yaw jumps. Reverse yaw counted at 30% to prevent premature "360 complete".

**Detection confirmation**: Requires 3 consistent frames — same class, cx within 80px, depth within 500mm. During confirmation, scan slows to 40%.

If full 360 with no lock: picks nearest from scan list.

### State 2: TURN_TO_TARGET

**Purpose**: Rotate to center the target in the camera frame.

**Core equation**:
```
pixel_offset = target_cx - 320
angular_vel = -0.003 * pixel_offset
```

100px right of center -> w = -0.30 rad/s (turn right)
50px left of center  -> w = +0.15 rad/s (turn left)

Negative sign: camera x-axis is opposite to rotation direction.

**Motor deadband override**: If |w| < 0.04, force to 0.04. Motors physically can't spin slower.

**EMA smoothing**: `w = 0.5 * raw + 0.5 * previous`. Filters bbox jitter.

**Transition**: |pixel_offset| < 50px -> APPROACH.

**When lost**: Coasts at last angular velocity. After 50 frames -> rescan.

### State 3: APPROACH

**Purpose**: Drive toward target while keeping it centered.

**Speed control**:
```
dist_ratio = (cam_z - 250) / 1100     # normalized 0 to 1
v = 0.04 + (0.25 - 0.04) * dist_ratio
```
At 1350mm: v = 0.25 m/s (full). At 800mm: v = 0.145. At 250mm: v = 0.04 (minimum).

**Softer steering**: Kp = 0.002 (not 0.003). Less swerving at speed.

**S-curve startup ramp**:
```
ramp = 0.5 * (1 - cos(pi * elapsed / 1.5))
v *= ramp
w *= ramp
```
Zero jerk at start and end. Both linear and angular ramped.

**Dual stop condition**:
- Primary: `base_x <= 200mm` (from camera-to-base_link transform)
- Fallback: `cam_z <= 250mm`

**When lost**: Coast forward at 0.04 m/s. If lost too long at close range -> stop (probably at target).

### State 4: ALIGN

**Purpose**: Final precise centering before arm pickup.

Same P controller as TURN (Kp = 0.003, deadband override), but:
- Must be centered within 30px
- If base_x > 250mm, creep forward at 0.04 m/s
- Need 5 stable frames before declaring done

When done: publishes to `/pickup_request` for arm.

---

## The Detection Pipeline

### TRT Poll Thread (20Hz background)

```
HTTP GET /detection -> JSON parse -> confidence check -> spatial filter -> store
```

### Filtering

| Filter | Scan | Tracking | Why |
|---|---|---|-----|
| Max depth | 2500mm | 3000mm | Don't chase far objects during scan |
| Min cy (top of image) | 25% | 20% | Top of frame = not on floor |
| Max bbox area | 15% | 25% | Large = walls, people |
| Min bbox area | 0.3% | 0.3% | Tiny = noise |

### Target Matching (_find_target_in_detections)

Three-tier fallback:
1. **Position match**: Detection within 80px (150px during TURN) of last known position
2. **Class match**: Same class name, closest to last position
3. **Any nearby**: Any detection within 200-300px radius

---

## Showcase Talking Points

### 30-second version:
"The robot scans by rotating in place. When the camera detects waste confirmed over 3 frames, it locks on and uses a P controller to center the object in the camera frame. Then it drives toward it with distance-proportional speed and smooth cosine acceleration. A softer controller gain during approach prevents swerving. The teensy bridge converts the velocity commands to differential wheel speeds and adds heading hold to fight castor drift. The whole system runs at 20-30Hz."

### If they ask about smoothing:
"At 30 FPS, the raw bbox center has about 8 pixels of noise. We apply an EMA filter with alpha 0.5 to cut that in half, then cap the angular velocity and enforce a motor deadband of 0.04 rad/s — below that, the motors physically can't spin. The teensy bridge adds another layer with a 0.3 m/s^2 acceleration limit."

### If they ask about the P controller:
"We use two P gains — 0.003 during turning for aggressive centering, and 0.002 during approach to reduce swerving. The output is angular velocity in rad/s, proportional to how many pixels the target is off-center. 100 pixels off-center produces 0.3 rad/s of rotation."

### If they ask why not PID:
"At 30 FPS, the measurements are clean enough that integral and derivative terms add more problems than they solve. The integral causes windup when the target is temporarily lost, and the derivative amplifies noise. Pure P with EMA smoothing is sufficient."

---

## Learning Plan

### Phase 1: Fundamentals (30 min)

**Topics:**
1. Differential drive kinematics — v, w -> left/right wheel speeds
2. Dead reckoning odometry — ticks -> position
3. P controller — error * gain = output
4. EMA filter — what alpha does, responsiveness vs smoothness tradeoff

**Questions:**
1. The robot needs to drive at 0.15 m/s while turning left at 0.10 rad/s. What are the left and right wheel velocities?
2. The left encoder reads 3780 more ticks than last reading, right reads 3780. How far did the robot move? Did it turn?
3. The target is 80px to the right of center. With Kp = 0.003, what angular velocity is commanded? Which direction?
4. Your EMA has alpha = 0.5, current filtered value is 0.10 rad/s, new raw value is 0.20 rad/s. What's the new filtered value?

### Phase 2: State Machine Logic (30 min)

**Topics:**
1. State transitions — triggers
2. SCAN confirmation — why 3 frames, resets
3. APPROACH speed profile — distance to speed mapping
4. Target matching — 3-tier fallback
5. Lost target handling — coast vs rescan vs stop

**Questions:**
5. During SCAN, the robot detects a cup at 1500mm for 2 frames, loses it for 1 frame, then sees it again. Does it lock on?
6. In APPROACH, cam_z reads 700mm. What forward speed is commanded (before ramp)?
7. The robot is in APPROACH and loses the target. cam_z was 400mm. What happens?
8. During TURN, a detection is 250px from last known position. Does _find_target_in_detections return it?

### Phase 3: Smoothing & Controls (30 min)

**Topics:**
1. Why P-only (not PID) at 30fps
2. S-curve ramp math — cosine profile, zero jerk
3. Motor deadband — physical cause and software fix
4. Heading hold — fighting castor drift
5. Two-Kp strategy — softer gain during approach

**Questions:**
9. Why would Ki be harmful if the target disappears for 20 frames then comes back?
10. At t = 0.5s into approach (ramp_time = 1.5s), what fraction of full speed is the robot at?
11. P controller outputs 0.02 rad/s. What actually gets sent to motors?
12. Robot drives straight at 0.12 m/s, heading drifts 0.05 rad. What does heading hold produce?

### Phase 4: System Integration (20 min)

**Topics:**
1. Thread safety — camera_lock, two threads
2. TRT communication — HTTP polling, stale detection, DEPTH_MAX_MM
3. ROS2 topic flow — /cmd_vel, /odom, /robot_state, /pickup_request
4. Calibration chain — how constants feed into each other

**Questions:**
13. What happens if the TRT server goes down for 3 seconds during APPROACH?
14. Why does the poll thread use `Connection: close` on HTTP requests?
15. The cmd_vel timeout is 0.5s. What if the tracker crashes but bridge keeps running?
16. If wheel_radius is wrong by 10%, which behaviors break?

---

## Answers

1. `v_left = 0.15 - 0.10 * 0.235 = 0.1265 m/s`, `v_right = 0.15 + 0.10 * 0.235 = 0.1735 m/s`
2. Distance = `(3780/7560) * 2pi * 0.05232 = 0.1645m`. No turn — both wheels moved equally.
3. `w = -0.003 * 80 = -0.24 rad/s`. Turns right (clockwise).
4. `0.5 * 0.20 + 0.5 * 0.10 = 0.15 rad/s`
5. No — confirm count reaches 2, then resets to 0 when detection disappears (no gap tolerance in this version).
6. `dist_ratio = (700-250)/1100 = 0.409`. `v = 0.04 + 0.21 * 0.409 = 0.126 m/s`
7. Lost at close range (<500mm) for 50 frames -> `drive_only_done = True`, goes IDLE. Probably already at target.
8. During TURN, max_radius = 300px. 250 < 300. Yes, returns it.
9. While target is gone, pixel error stays large, integral winds up. When target reappears, accumulated integral causes huge overshoot — robot spins way past center.
10. `ramp = 0.5 * (1 - cos(pi * 0.5/1.5)) = 0.5 * (1 - cos(60deg)) = 0.5 * 0.5 = 0.25`. 25% speed.
11. 0.02 < 0.04 (deadband), overridden to 0.04 rad/s in the error direction. Without this, motors wouldn't move.
12. `w = 2.0 * 0.05 = 0.10 rad/s` corrective rotation.
13. Poll returns URLError, consecutive_errors increments. latest_detections stays empty. target_lost_count increments. After 50 frames (2.5s), decides based on last depth.
14. Prevents HTTP keep-alive accumulating stale state. Each request is fresh.
15. cmd_vel_timeout fires after 0.5s of no messages. Sends SETVEL 0.0 0.0. Motors stop safely.
16. Odometry position is wrong (thinks it moved more/less). BUT: scan yaw uses left/right ratio (unaffected by radius). Approach stop uses cam_z (unaffected). Heading hold uses yaw (unaffected). Main break: if other nodes rely on /odom position.

---

## Known Issue: DEPTH_MAX_MM = 600

The TRT server (`camera_detect_trt.py`) only reports detections within 600mm. This limits driving — the tracker can't see targets until very close. Needs to be changed to 3000mm for driving range. Will change later.

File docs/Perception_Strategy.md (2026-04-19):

# Perception Strategy — RECLAIM

> This doc captures all research, decisions, and implementation details for the perception pipeline. Every perception-related agent should read this before writing code.

## Problem Statement

First training attempt (Approach 1) failed badly:
- Recyclable AP50 = 0.45
- Compost AP50 = 0.00
- Landfill AP50 = 0.02

**Root cause: data imbalance, NOT model architecture.** TACO has almost no compost images, and Flickr download links are broken. The 3-class broad taxonomy (recyclable/compost/landfill) is also visually incoherent. "Recyclable" covers glass bottles, aluminum cans, and cardboard, which share no visual features.

## Key Decision: Fine-Grained Classes Mapped to Bins

**Train on 10-15 specific item classes, then map to bins via a lookup table.** This is strongly supported by the literature and gives three advantages:
1. Better per-class accuracy from visually coherent classes
2. Flexibility to change bin assignments without retraining
3. More interpretable results for demo

```python
BIN_MAP = {
    # Recyclable bin
    'plastic_bottle': 'recyclable', 'aluminum_can': 'recyclable',
    'glass_bottle': 'recyclable', 'cardboard': 'recyclable',
    'paper': 'recyclable', 'metal_lid': 'recyclable',
    # Compost bin
    'banana_peel': 'compost', 'food_waste': 'compost',
    'napkin': 'compost', 'paper_cup': 'compost',
    # Landfill bin
    'chip_bag': 'landfill', 'wrapper': 'landfill',
    'styrofoam': 'landfill', 'plastic_bag': 'landfill',
    'cigarette': 'landfill',
}
```

This taxonomy can be adjusted based on what datasets are available. The exact classes matter less than having visually distinct, balanced classes.

## Datasets to Use

| Dataset | Images | Classes | Why |
|---|---|---|-----|
| **detect-waste (merged)** | 28,000+ | 7 unified | Best merged corpus, includes TACO + 6 others. `github.com/wimlds-trojmiasto/detect-waste` |
| **GARBAGE CLASSIFICATION 3 (Roboflow)** | 10,000+ | 7 material types | `universe.roboflow.com/material-identification/garbage-classification-3` |
| **Drinking Waste** | 9,640 | 4 beverage containers | Good for recyclable bottles/cans. `kaggle.com/datasets/arkadiyhacks/drinking-waste-classification` |
| **RealWaste** | 4,752 | 9 classes inc. food organics | Critical for compost class. `archive.ics.uci.edu/dataset/908/realwaste` |
| **ZeroWaste (CVPR 2022)** | 4,503 | 4 recyclable types | `github.com/dbash/zerowaste` |

**For merging datasets:** Use FiftyOne (`pip install fiftyone`) for format conversion and dataset merging.

**Minimum target: 300 images per class.** Duplicate/augment minority classes to reach this.

## Training Configuration (YOLOv8n)

```python
from ultralytics import YOLO
model = YOLO("yolov8n.pt")  # COCO pretrained
model.train(
    data="waste.yaml",
    epochs=100,
    imgsz=640,
    fl_gamma=1.5,          # Enable focal loss (default 0.0 = disabled)
    image_weights=True,     # Sample images by class frequency
    copy_paste=0.3,         # Paste minority instances into other images
    mosaic=1.0,             # Combines 4 images — increases minority exposure
    mixup=0.15,             # Blend images together
    optimizer='AdamW',      # Better than SGD for small datasets
    lr0=0.001,              # Lower LR for fine-tuning
    freeze=10,              # Freeze backbone for first pass (30 epochs), then unfreeze
    patience=50,            # Early stopping
)
```

**Key augmentation**: `copy_paste=0.3` is the single most impactful technique for long-tail class distributions (CVPR 2021, Ghiasi et al.).

**Offline augmentation for minority classes** (3-5x copies using Albumentations):
```python
import albumentations as A
transform = A.Compose([
    A.RandomBrightnessContrast(p=0.5),
    A.GaussNoise(p=0.3),
    A.MotionBlur(blur_limit=7, p=0.3),
    A.RandomShadow(p=0.3),
    A.CLAHE(p=0.3),
], bbox_params=A.BboxParams(format='yolo'))
```

**Target accuracy: mAP50 >= 0.70.** Published results show 0.70-0.85 is achievable with balanced data on YOLOv8n.

## Fallback: Two-Stage Pipeline

If single-stage YOLO underperforms after fixing data:
1. Train YOLOv8 as binary "waste" vs "background" detector (high recall)
2. Crop detected regions
3. Classify crops with MobileNetV2 trained on balanced image-level datasets
4. This approach achieved 97.8% classification accuracy (Edge Impulse) and 70% AP + 75% classification (detect-waste project)

## OAK-D Lite Depth Pipeline

### SpatialDetectionNetwork (Recommended)

The OAK-D Lite can run YOLO + stereo depth on-device, outputting (X, Y, Z) in millimeters for every detection. This is the recommended approach.

**On-device performance:**
- YOLOv8n @ 416x416: ~31 FPS on Myriad X
- YOLOv8n @ 640x640: ~14 FPS on Myriad X

**Depth accuracy:** <2% error within 3m (±2cm at 1m, ±4cm at 2m). Min depth ~35cm standard, ~20cm with extended disparity. Sufficient for pickup at 0.5-2.0m.

**To use SpatialDetectionNetwork, the model must be converted to .blob format:**
```bash
# Export to ONNX
yolo export model=best.pt format=onnx imgsz=416 simplify=True opset=12

# Convert to blob via blobconverter
pip install blobconverter
```
```python
import blobconverter
blob_path = blobconverter.from_onnx(
    model="best.onnx",
    data_type="FP16",
    shaves=6,
    optimizer_params=["--mean_values=[0,0,0]", "--scale_values=[255,255,255]"]
)
```

Or use Luxonis online tool: `tools.luxonis.com`

**Critical: Use ONNX opset 12 and OpenVINO 2021.4** for best Myriad X compatibility.

### Alternative: YOLO on Jetson GPU + Depth from OAK-D

If SpatialDetectionNetwork doesn't work (e.g., blob conversion fails):
- Stream RGB + depth from OAK-D to Jetson
- Run YOLO on Jetson GPU with TensorRT (~52-66 FPS at 640x640)
- Sample depth at bounding box center
- Convert pixel (cx, cy, z_mm) to 3D using camera intrinsics

This adds complexity (manual depth sampling, RGB-depth alignment) but gives more flexibility with model choice.

### Jetson TensorRT Benchmarks (Orin NX)

| Model | Precision | Resolution | FPS | mAP50 (COCO) |
|---|---|---|-----|---|
| YOLOv8n | FP16 | 640x640 | ~52 | 52.5 |
| YOLOv8n | INT8 | 640x640 | ~66 | ~51.5 |
| YOLOv8s | FP16 | 640x640 | ~35 | 61.8 |

Export for TensorRT:
```python
model = YOLO("best.pt")
model.export(format="engine", imgsz=640, half=True, int8=True, device=0)
```

## YOLO26 Status: DO NOT USE YET

YOLO26n is ~3 mAP points better than YOLOv8n but:
- **Myriad X .blob compatibility is UNVERIFIED** as of March 2026
- Luxonis tools.luxonis.com does not list YOLO26 support
- NMS-free output tensor format may break DepthAI's YOLO parser
- The 3 mAP gain is negligible compared to 20-30 point gain from data fixes

**Decision: Stick with YOLOv8n for the demo.** Only switch if someone verifies blob conversion works.

## DepthAI v3 API Reminders

DepthAI 3.3.0 is installed. The v3 API is different from v2. See CLAUDE.md for the full v2→v3 migration reference.

**NOTE:** The SpatialDetectionNetwork code examples in the research doc use v2 API patterns (ColorCamera, XLinkOut, setBoardSocket, etc.). These WILL NOT WORK with DepthAI v3. When implementing SpatialDetectionNetwork, check DepthAI v3 docs at `docs.luxonis.com/software-v3/depthai/` for the correct v3 equivalents. The concepts are the same but the method names changed.

## Coordinate Transform: Camera → Robot

Transform chain: `map → odom → base_link → camera_link → camera_optical_frame`

- `map → odom`: from SLAM Toolbox / AMCL
- `odom → base_link`: from wheel odometry (Teensy encoders)
- `base_link → camera_link`: static transform (camera mount position)
- `camera_link → camera_optical_frame`: automatic from depthai-ros URDF

```python
import tf2_ros
from geometry_msgs.msg import PointStamped

tf_buffer = tf2_ros.Buffer()
tf_listener = tf2_ros.TransformListener(tf_buffer, node)

# Transform detection from camera frame to map frame
point = PointStamped()
point.header.frame_id = 'oak_rgb_camera_optical_frame'
point.point.x, point.point.y, point.point.z = x_cam, y_cam, z_cam
map_point = tf_buffer.transform(point, 'map', timeout=Duration(seconds=1.0))
```

## Navigation to Waste

Use `nav2_simple_commander` to navigate to 0.5m from detected waste, then visual servo for final alignment using YOLO bounding box centering via `/cmd_vel`.

## Arm Pickup Strategy

**UPDATE (March 2026): Pursuing MoveIt2 for IK-based picking.**

The original plan was to skip MoveIt2 and use pre-defined joint poses only. We're now pursuing MoveIt2 so the arm can compute inverse kinematics to reach arbitrary 3D positions detected by the camera. The pre-defined pose sequences (PICKUP command in firmware) remain as a fallback.

**Full pipeline:**
1. Camera detects waste via YOLO, stereo depth gives 3D position in camera frame
2. tf2 transforms coordinates from camera frame to arm base frame (static transform)
3. MoveIt2 computes IK solution for the target position
4. ros2_control hardware interface sends joint commands to Teensy via serial
5. Gripper closes (angle determined by object class or bounding box width)
6. Arm lifts and moves to appropriate bin using pre-defined bin poses

**Fallback (if MoveIt2 timeline slips):** Use pre-defined pose sequences with the PICKUP firmware command. Robot drives to ~30cm from waste, arm executes fixed pick sequence. Less precise but already working.

See `Camera_Placement_Plan.md` for camera mounting details and the camera-to-arm transform.

## Reference Repos

| Repo | Why it's useful |
|---|---|
| **MARIO-COM** (`github.com/bharadwaj-chukkala/MARIO-COM`) | Closest match: ROS2 + TurtleBot3 + Nav2 + arm pickup |
| **detect-waste** (`github.com/wimlds-trojmiasto/detect-waste`) | Best merged dataset + training scripts |
| **RoboSort** (`github.com/qppd/robo-sort`) | YOLO + LIDAR + 6DOF arm, serial protocol |
| **Trash Sorting Robot** (`github.com/bandofpv/Trash-Sorting-Robot`) | SSD + RPi + Dobot Arm, full BOM |
| **WasteGAN** (`github.com/bach05/wastegan`) | Synthetic data for rare waste classes (+30% minority improvement) |
| **Waste Detection YOLOv8** (`github.com/boss4848/waste-detection`) | YOLOv8 + Streamlit + Colab notebook |

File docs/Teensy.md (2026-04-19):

# Teensy 4.1 — RECLAIM Reference

## Connection

- **USB Device:** `/dev/ttyACM0` on MIC-711
- **Baud Rate:** 115200
- **USB Bus:** Bus 001 (USB 2.0)
- **lsusb ID:** `16c0:0486 Van Ooijen Technische Informatica Teensyduino`

## Pin Map

| Pin | Function | Component | Wire Color (from Cirkit guide) |
|-----|---|---|---|
| 2 | PWM (speed) | MD10C #1 — Left motor | — |
| 3 | DIR (direction) | MD10C #1 — Left motor | — |
| 4 | PWM (speed) | MD10C #2 — Right motor | — |
| 5 | DIR (direction) | MD10C #2 — Right motor | — |
| 6 | Encoder Ch A | Left motor encoder | — |
| 7 | Encoder Ch B | Left motor encoder | — |
| 8 | Encoder Ch A | Right motor encoder | — |
| 9 | Encoder Ch B | Right motor encoder | — |
| 10 | Servo PWM | Base rotation (MG996R) | — |
| 11 | Servo PWM | Shoulder (MG996R) | — |
| 12 | Servo PWM | Elbow (MG996R) | — |
| 13 | Servo PWM | Wrist Pitch (MG996R) | — |
| 14 | Servo PWM | Wrist Rotate (MG996R) | — |
| 15 | Servo PWM | Gripper (MG996R) | — |
| 3V | Encoder VCC | Both encoders (3.3V) | — |
| GND | Ground | Ground bus | — |

**Encoder power:** 3.3V from Teensy 3V pin. Output signals are 3.3V, directly compatible with Teensy GPIO. Do NOT use 5V — Teensy GPIO is NOT 5V tolerant. If signals are noisy at 3.3V, add a BOB-12009 level shifter.

## Motor Drivers (2x Cytron MD10C)

- PWM frequency: 20kHz recommended
- DIR pin: HIGH = forward, LOW = reverse
- Accepts 3.3V logic directly from Teensy (no level shifter needed)
- NOT MDD10A (that's a dual-channel board, we have two single-channel MD10C)

## Servos (6x MG996R)

- All joints use the same servo model (MG996R)
- Powered by XINGYHENG 20A 300W buck converter (12V in, ~6V out)
- Power distributed via 4x Wago 221-415 lever-nuts
- 4700-10000uF bulk capacitor on servo power bus (prevents brownout on simultaneous movement)
- PWM signal from Teensy pins 10-15 (3.3V logic, MG996R accepts this)

| Servo Pin | Joint | Safe Range (degrees) |
|---|---|---|
| 10 | Base rotation | TBD (test tomorrow) |
| 11 | Shoulder | TBD (test tomorrow) |
| 12 | Elbow | TBD (test tomorrow) |
| 13 | Wrist Pitch | TBD (test tomorrow) |
| 14 | Wrist Rotate | TBD (test tomorrow) |
| 15 | Gripper | TBD (test tomorrow) |

## Encoders (JGB37-520 motors)

- Hall-effect quadrature encoders (2 channels per motor)
- 6-pin connector per motor: M1, M2 (motor power), VCC, GND, OutA, OutB (encoder)
- Counts per revolution: TBD (need to measure)
- Use hardware interrupts on Teensy for accurate counting

## Flashing Firmware

PlatformIO is pip-installed on the MIC-711 at `/home/mic-711/.local/bin/pio` (NOT in the conda env). Use `$(which pio)` or the full path when running with `sudo`.

**Project location:** `~/reclaim_ws/tests/teensy_hello/` (basic serial test)
**Active firmware:** `~/reclaim_ws/src/reclaim_control/firmware/`

### platformio.ini

```ini
[env:teensy41]
platform = teensy
board = teensy41
framework = arduino
upload_protocol = teensy-cli
monitor_speed = 115200
```

### CRITICAL: Flash Procedure (EXACT steps that work)

Flashing MUST be done on the MIC-711 (not Mac — Mac USB hub causes detection issues).
PlatformIO is installed in the `ros_env` conda environment on the MIC-711.

**The ONLY flash command that works:**
```bash
# Step 1: Fix permissions on hidraw devices (REQUIRED every time)
sudo chmod 666 /dev/hidraw*

# Step 2: Flash with sudo (REQUIRED — without sudo it ALWAYS fails with "Permission denied")
cd ~/reclaim_ws/tests/teensy_hello    # or whatever project directory
sudo $(which pio) run --target upload
```

**Why `sudo` is required:** The `teensy_loader_cli` needs raw USB access to the HID bootloader device. Even with udev rules and chmod, it fails without sudo. Don't waste time trying without sudo.

**Why `$(which pio)` is needed:** `sudo` doesn't inherit the conda PATH, so `sudo pio` gives "command not found". The `$(which pio)` resolves to the full path before sudo runs it.

**When prompted "press the reset button":** Press the small physical pushbutton on the Teensy board. This puts it in bootloader mode so the loader can flash it.

**Common errors and fixes:**

| Error | Fix |
|---|-----|
| `Found device but unable to open` | Run `sudo chmod 666 /dev/hidraw*`, then unplug/replug Teensy, retry with `sudo` |
| `Permission denied` | You forgot `sudo`. Use `sudo $(which pio) run --target upload` |
| `Unable to open /dev/ttyACM0 for reboot request` | Normal warning when reflashing. Teensy reboots into bootloader, press the button |
| `sudo: pio: command not found` | Use `sudo $(which pio)` not `sudo pio` |
| `Waiting for Teensy device...` forever | Press the physical button on the Teensy |
| ModemManager grabbing the port | `sudo systemctl stop ModemManager && sudo systemctl disable ModemManager` |

**Non-interactive SSH flash command (for agents):**
```bash
ssh mic "source ~/miniforge3/etc/profile.d/conda.sh && conda activate ros_env && cd ~/reclaim_ws/tests/teensy_hello && sudo chmod 666 /dev/hidraw* && sudo \$(which pio) run --target upload"
```
Note: User must press the Teensy button when prompted. This cannot be automated.

### Permissions

Udev rules on the MIC-711:
```
/etc/udev/rules.d/99-teensy.rules:
SUBSYSTEM=="hidraw", ATTRS{idVendor}=="16c0", MODE="0666"
```

Even with this rule, `sudo` is still required for flashing. The rule helps but doesn't fully solve it.

For serial access after flashing:
```bash
sudo chmod 666 /dev/ttyACM0
```

### Serial communication from MIC-711

```python
import serial
s = serial.Serial('/dev/ttyACM0', 115200, timeout=2)
line = s.readline().decode().strip()  # read
s.write(b'command\n')                  # write
s.close()
```

**Non-interactive SSH serial command (for agents):**
```bash
ssh mic "source ~/miniforge3/etc/profile.d/conda.sh && conda activate ros_env && sudo chmod 666 /dev/ttyACM0 && python3 -c \"import serial; s=serial.Serial('/dev/ttyACM0',115200,timeout=2); import time; time.sleep(1); [print(s.readline().decode().strip()) for _ in range(3)]; s.close()\""
```

## Available Firmware

All firmware lives in `reclaim_ws/src/reclaim_control/firmware/`.

### teensy_hello (basic serial test)
- Location: `~/reclaim_ws/tests/teensy_hello/`
- Sends `[heartbeat] uptime=Ns` every second
- Echoes back any received serial messages as `[echo] <message>`
- Blinks built-in LED as heartbeat indicator
- **Status:** Flashed and verified March 6, 2026. Serial comms confirmed at 115200 baud.

### servo_test (interactive 6-servo calibration tool)
- Location: `reclaim_ws/src/reclaim_control/firmware/servo_test/`
- **Raw microsecond control** with per-servo calibration and joint zero references
- MG996R servos rated 0-270°, pulse range 400-2600us
- Servos start **DETACHED** (no PWM on boot) — prevents spaz on power-up
- Motor driver pins (2-5) driven LOW on boot — prevents drive motors from spinning

**Controls:**
- `1`-`6` = select servo (1=Base, 2=Shoulder, 3=Elbow, 4=WristPitch, 5=WristRotate, 6=Gripper)
- `d`/`a` = +/- 10us (coarse), `D`/`A` = +/- 2us (fine)
- `c` = center (1500us)
- `[` = set current pulse as calMin (0°), `]` = set current pulse as calMax (270°)
- `z` = set JOINT 0° reference (attaches servo at 1500us if not yet active — hold the arm!)
- `m` = save JOINT MIN (relative degrees), `M` = save JOINT MAX (relative degrees)
- `p` = print all positions, `h` = help

**Calibration workflow:**
1. Manually position each servo to its physical center by hand
2. Press `z` to attach at 1500us and set joint zero reference (minimizes initial jump)
3. Use `d`/`a` to find mechanical limits in each direction
4. Press `m` at min limit, `M` at max limit to record relative joint range
5. Optionally press `[`/`]` to set pulse calibration endpoints

- **Status:** Extensively updated March 8, 2026. All 6 servos respond on pins 10-15. Motor spaz-on-boot fixed. Safe angle ranges still TBD (calibration not yet performed).
- **TODO:** Calibrate all 6 joints using the workflow above. Record values and update arm_commander.

### arm_commander (production arm controller with quintic interpolation)
- Location: `reclaim_ws/src/reclaim_control/firmware/arm_commander/`
- Serial protocol: `SET a1 a2 a3 a4 a5 a6 [T_ms]`, `GET`, `TEACH <name>`, `HOME`, `STOP`, `NUDGE <joint> <deg>`, `LIMITS`, `HELP`
- Quintic (minimum-jerk) interpolation at 50Hz for smooth acceleration/deceleration
- Configurable safe angle limits per joint (edit SAFE_MIN/SAFE_MAX arrays in source)
- Responds `MOVING ... T=Nms` on move start, `DONE` + `ANGLES ...` on completion
- Companion tool: `scripts/pose_teacher.py` (interactive CLI for teaching and saving poses to `config/poses.yaml`)
- **Status:** Written March 8, 2026. NOT yet flashed. Flash this after finding safe limits with servo_test.

### motor_encoder_test (automated + manual motor control)
- Location: `reclaim_ws/src/reclaim_control/firmware/motor_encoder_test/`
- **main.cpp:** Automated test. Runs left motor (pins 2/3) forward at 50%, stop, reverse at 50%, stop, then speed ramp 0-255. Reads encoder ticks (pins 6/7) throughout and calculates RPM (assumes 210 ticks/rev: 7 PPR, 30:1 gearbox).
- **manual_control.cpp:** Interactive WASD control. `w` forward, `s` reverse, `x` stop, `+/-` speed, `r` reset encoder count. Prints ticks every 200ms while running.
- **Status:** Auto test verified March 7, 2026. Motor forward/reverse works. Encoder ticks read correctly. ~660 ticks/200ms at 50% PWM. Manual control firmware written but not yet tested interactively.

## URDF

A minimal kinematic URDF skeleton is at `reclaim_ws/src/reclaim_control/urdf/reclaim_arm.urdf`. It defines all 6 joints with correct axis orientations but uses PLACEHOLDER link lengths. You must measure the physical arm and replace the TODO values before using it with MoveIt2.

Measurements needed (in meters): base-to-shoulder height, shoulder-to-elbow length, elbow-to-wrist length, wrist-to-gripper offset.

## Verified Test Results

| Test | Result | Date |
|---|---|---|
| USB detection on MIC-711 | `/dev/ttyACM0`, 115200 baud | March 6 |
| Serial heartbeat + echo | Working | March 6 |
| Servo response (all 6 pins 10-15) | Working | March 6 |
| Motor auto test (forward/reverse/ramp) | Working (left motor + encoder) | March 7 |
| Servo raw us control + joint zero | Working (firmware updated) | March 8 |
| Motor manual control | Firmware written, NOT yet tested | — |
| Servo calibration (safe ranges) | NOT YET DONE | — |

## Remaining Hardware Tasks

1. Wire motors to MD10C drivers (motor power from 12V fuse block), MD10C signal to Teensy pins 2-5
2. Wire encoder outputs to Teensy pins 6-9 (encoder VCC from Teensy 3.3V pin)
3. Flash and run `motor_encoder_test` to verify motor direction and encoder counting
4. Measure actual encoder counts per revolution (firmware assumes 210, verify this)
5. Find safe angle ranges for each servo joint using `servo_test` or `pose_teacher.py limits`
6. Update SAFE_MIN/SAFE_MAX in `arm_commander` firmware with real limits, then flash it
7. Teach named poses (home, pre_pick, pick_down, bin1/2/3_pre, bin1/2/3_drop) using `pose_teacher.py`
8. Measure arm link lengths and update URDF placeholder values
9. Build micro-ROS firmware that publishes `/odom` and subscribes to `/cmd_vel` + `/arm/command`

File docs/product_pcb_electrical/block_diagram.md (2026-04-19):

# RECLAIM Product — System Block Diagram
**Date:** March 25, 2026

---

## Power Architecture

```
┌─────────────────────────────────────────────────────────────────────┐
│                    25.6V LiFePO4 Battery (20Ah)                     │
│                         + BMS (30A)                                 │
└──────────────┬──────────────────────────────────────────────────────┘
               │ XT90 connector + antispark
               │
               ▼
    ┌──────────────────┐
    │  Latching E-STOP │──── Mushroom button (NC contact)
    │  + Power Relay   │
    └────────┬─────────┘
             │
    ┌────────▼──────────────────────────────────────────────────────┐
    │                    Main 25.6V Bus (fused)                      │
    └──┬──────────┬──────────────┬──────────────┬───────────────────┘
       │          │              │               │
       ▼          ▼              ▼               ▼
  [CubeMars   [DRV8243 L]  [DRV8243 R]    [25V→12V Buck]
   AK series   Drive Motor  Drive Motor     10A, 120W
   via CAN]    Left         Right           │
                                            ├──── Jetson Orin NX (12V, 25W)
                                            ├──── Livox Mid-360 (12V, 8W)
                                            │
                                        [12V→5V Buck]
                                            3A, 15W
                                            │
                                            ├──── USB Hub / Peripherals
                                            │
                                        [5V→3.3V LDO]
                                            500mA
                                            │
                                            ├──── STM32F405
                                            ├──── ICM-42688-P
                                            ├──── SN65HVD230 ×2
                                            └──── INA226 ×3
```

---

## Signal Architecture

```
                        ┌─────────────────────────────────┐
                        │         Jetson Orin NX           │
                        │  (ROS2 Humble, Nav2, YOLO)       │
                        └──────────────┬──────────────────┘
                                       │
                              micro-ROS over USB-UART
                                       │
                        ┌──────────────▼──────────────────────────────────┐
                        │              STM32F405RGT6                       │
                        │         (100Hz real-time control)                │
                        │                                                  │
                        │  ┌──────┐  ┌──────┐  ┌──────┐  ┌──────────┐   │
                        │  │TIM2  │  │TIM3  │  │TIM1  │  │ CAN1/2   │   │
                        │  │Enc L │  │Enc R │  │Spare │  │ ARM bus  │   │
                        │  └──┬───┘  └──┬───┘  └──────┘  └────┬─────┘   │
                        │     │         │                       │         │
                        │  ┌──▼─────────▼──────┐    ┌──────────▼──────┐  │
                        │  │   SPI1 Bus        │    │  SN65HVD230     │  │
                        │  │ DRV8243L + DRV8243R│    │  CAN Transceiver│  │
                        │  │ ICM-42688-P (IMU) │    └──────────┬──────┘  │
                        │  └───────────────────┘               │         │
                        │                                  CAN_H/CAN_L   │
                        │  ┌──────────────────┐                │         │
                        │  │  UART1 / GPIO    │    ┌───────────▼──────┐  │
                        │  │  WS2812B LEDs    │    │  CubeMars Arm    │  │
                        │  │  PT4115 PWM dim  │    │  AK70-10 (J1)    │  │
                        │  │  Bumper switches │    │  AK80-9  (J2)    │  │
                        │  │  E-stop feedback │    │  AK60-6  (J3)    │  │
                        │  └──────────────────┘    │  AK10-9  (J4)    │  │
                        │                          │  AK10-9  (J5)    │  │
                        │  ┌──────────────────┐    │  XM430   (J6)    │  │
                        │  │  I2C1 Bus        │    └──────────────────┘  │
                        │  │  INA226 ×3       │                          │
                        │  │  (power monitor) │                          │
                        │  └──────────────────┘                          │
                        └────────────────────────────────────────────────┘

     ┌──────────┐        ┌──────────┐        ┌───────────┐
     │ OAK-D Pro│        │Livox     │        │ WS2812B   │
     │ (USB3.0) │        │Mid-360   │        │ LED Ring  │
     │ → Jetson │        │(Ethernet)│        │ (Status)  │
     └──────────┘        │→ Jetson  │        └───────────┘
                         └──────────┘
```

---

## PCB Schematic Sections

### Section 1 — Power Input & Distribution
```
Net list:
  VBAT         = 25.6V battery positive
  GND          = Common ground
  VCC_25V      = Post-relay main bus
  VCC_12V      = After 25V→12V buck
  VCC_5V       = After 12V→5V buck
  VCC_3V3      = After 5V→3.3V LDO

Components:
  J1           = XT90 battery connector (VBAT, GND)
  SW1          = E-stop mushroom (NC, in series with VBAT)
  K1           = Power relay (Omron G5LE, 16A, 12V coil)
  F1           = 30A main fuse (VBAT to relay)
  F2           = 15A motor fuse (VCC_25V to DRV8243)
  F3           = 10A arm fuse (VCC_25V to CAN arm connector)
  F4           = 5A compute fuse (VCC_25V to buck)
  U1           = 25V→12V buck (LM2596 or TPS5430, 10A)
  U2           = 12V→5V buck (TPS5430, 3A)
  U3           = 5V→3.3V LDO (AMS1117-3.3, 1A)
  C1-C4        = Bulk caps on each rail (470uF, 25V rated or higher)
  C5-C8        = Ceramic decoupling (100nF per IC)
```

### Section 2 — STM32F405 MCU
```
Net list:
  NRST         = Reset pin (100nF to GND)
  BOOT0        = Boot mode select (pull to GND for normal boot)
  PA0-PA15     = GPIO bank A
  PB0-PB15     = GPIO bank B
  PC0-PC15     = GPIO bank C

Key pin assignments:
  PA8          = TIM1_CH1 — Encoder L Ch A
  PA9          = TIM1_CH2 — Encoder L Ch B
  PB4          = TIM3_CH1 — Encoder R Ch A
  PB5          = TIM3_CH2 — Encoder R Ch B

  PA5          = SPI1_SCK  — shared SPI bus
  PA6          = SPI1_MISO
  PA7          = SPI1_MOSI
  PB0          = SPI1_CS1  — DRV8243 Left CS
  PB1          = SPI1_CS2  — DRV8243 Right CS
  PB2          = SPI1_CS3  — ICM-42688-P CS

  PB8          = CAN1_RX   — Arm CAN bus
  PB9          = CAN1_TX
  PB12         = CAN2_RX   — Spare CAN bus
  PB13         = CAN2_TX

  PA2          = USART2_TX — micro-ROS to Jetson
  PA3          = USART2_RX

  PC6          = TIM8_CH1  — WS2812B data
  PC7          = TIM8_CH2  — PT4115 PWM dim
  PC8          = GPIO OUT  — E-stop relay control
  PC9-PC12     = GPIO IN   — Bumper switches (×4, pull-up)

  PB6          = I2C1_SCL  — INA226 bus
  PB7          = I2C1_SDA

  PA13         = SWDIO     — Debug/programming
  PA14         = SWDCK
  NRST         = Reset

Components:
  U4           = STM32F405RGT6 (LQFP-64)
  Y1           = 8MHz crystal (main clock → PLL to 168MHz)
  C9-C10       = 22pF load caps for crystal
  R1           = 10k pull-up on NRST
  R2           = 10k pull-down on BOOT0
  J2           = SWD debug header (4-pin: SWDIO, SWDCK, VCC, GND)
  J3           = USB Type-C (USART2 bridge via CP2102N)
```

### Section 3 — Motor Drivers (DRV8243 ×2)
```
For each channel (Left and Right identical):

Net list:
  VM           = VCC_25V (motor power)
  VCC          = VCC_3V3 (logic power)
  SPI_CS       = Chip select from STM32
  SPI_SCLK     = SPI clock
  SPI_SDI      = SPI data in
  SPI_SDO      = SPI data out
  FAULTZ       = Fault output (active low, to STM32 GPIO)
  OUT1, OUT2   = H-bridge outputs to motor
  ISENSE       = Current sense output (to STM32 ADC)

Components:
  U5           = DRV8243HPWPRQ1 (PWP-17 package)
  R3           = 10mΩ current sense resistor (0.5W)
  C11          = 100nF VCC decoupling
  C12          = 10uF VM bulk cap
  C13          = 100nF VM decoupling
  TVS1         = SMBJ28A TVS diode (VM rail, clamp motor back-EMF)
  J4           = Motor output connector (3-pin: OUT1, OUT2, GND)
  J5           = Encoder connector (6-pin: A, B, VCC_3V3, GND, ×2)
```

### Section 4 — CAN Bus Interface
```
Two identical transceivers (Arm CAN + Spare):

Components:
  U6           = SN65HVD230DR (SO-8)
  R4           = 120Ω termination resistor (between CAN_H and CAN_L)
  C14          = 100nF decoupling on VCC pin
  J6           = CAN arm connector (3-pin: CAN_H, CAN_L, GND)
                 Daisy chained: J1→AK70-10→AK80-9→AK60-6→AK10-9→AK10-9→XM430
```

### Section 5 — IMU (ICM-42688-P)
```
Components:
  U7           = ICM-42688-P (LGA-14)
  C15          = 100nF decoupling
  C16          = 1uF bulk cap
  R5           = DNP (interrupt pull-up, optional)

Notes:
  - Mount as close to PCB center of mass as possible
  - Align chip X/Y axes with robot X/Y axes
  - Keep away from motor driver switching noise
  - Use ground plane pour directly under chip
```

### Section 6 — Power Monitoring (INA226 ×3)
```
One per rail: 25V bus, 12V bus, 5V bus

Components per channel:
  U8-U10       = INA226AIDGST (SOT-23-8)
  R6-R8        = 10mΩ shunt resistor (1%, 1W)
  C17-C19      = 100nF decoupling

I2C addresses:
  INA226 #1 (25V rail): A0=GND, A1=GND → addr 0x40
  INA226 #2 (12V rail): A0=VCC, A1=GND → addr 0x41
  INA226 #3 (5V rail):  A0=GND, A1=VCC → addr 0x44
```

### Section 7 — Status LED & Work Light
```
WS2812B LED Ring:
  R9           = 470Ω series resistor on data line (prevent reflections)
  C20          = 100uF across power pins (close to LED ring)
  J7           = 3-pin connector (5V, GND, DATA)
  PWR          = VCC_5V (WS2812B runs at 5V, data from 3.3V STM32 OK)

Work Light (Cree XHP35):
  U11          = PT4115 (constant current LED driver)
  R10          = 0.1Ω set resistor (sets current to ~1A = 350 lumens)
  L1           = 22uH inductor (PT4115 switching)
  D1           = SS34 Schottky diode (PT4115 freewheel)
  LED1         = Cree XHP35 (on thermal pad, bolt to chassis)
  J8           = 2-pin LED connector
  PWM input    = From STM32 PC7 (dimming)
```

### Section 8 — Safety & E-Stop
```
E-Stop circuit:
  SW1          = Latching mushroom (NC contacts, in VBAT line)
  K1           = Omron G5LE relay (16A, 12V coil)
  Q1           = IRLZ44N MOSFET (relay coil driver, from STM32 PC8)
  D2           = 1N4007 flyback diode across relay coil
  R11          = 1kΩ gate resistor for Q1

Bumper switches (×4):
  SW2-SW5      = Microswitch (NO, one per corner)
                 Connected to PC9-PC12 with internal pull-ups enabled
                 Any switch triggered → STM32 GPIO interrupt → E-stop

Logic:
  Normal:      STM32 PC8 HIGH → Q1 ON → Relay coil energized → K1 NC open
               (relay bypassed, power flows through NC contact of mushroom)

  E-stop hit:  Mushroom opens NC → power cut regardless of software
  Software stop: STM32 PC8 LOW → Q1 OFF → Relay de-energizes → motor power cut
```

### Section 9 — External Connectors
```
J_JETSON     = 4-pin (USB-C or UART: TX, RX, VCC_5V, GND)
J_LIDAR      = 3-pin (12V, GND, Ethernet via magnetics to RJ45)
J_CAMERA     = 2-pin (USB3.0 to Jetson directly, power only from PCB)
J_CAN_ARM    = 3-pin (CAN_H, CAN_L, GND) — to first CubeMars joint
J_MOTOR_L    = 3-pin (OUT1, OUT2, GND)
J_MOTOR_R    = 3-pin (OUT1, OUT2, GND)
J_ENC_L      = 6-pin (A, B, VCC, GND, ×2 for quadrature)
J_ENC_R      = 6-pin
J_LED_STATUS = 3-pin (5V, GND, DATA)
J_LED_WORK   = 2-pin (LED+, LED-)
J_ESTOP      = 2-pin (mushroom switch contacts)
J_BUMPER_FL  = 2-pin (front-left bumper)
J_BUMPER_FR  = 2-pin (front-right bumper)
J_BUMPER_RL  = 2-pin (rear-left bumper)
J_BUMPER_RR  = 2-pin (rear-right bumper)
J_SWD        = 4-pin (SWDIO, SWDCK, VCC, GND) — programming header
J_BATTERY    = XT90 (VBAT+, GND)
```

---

## PCB Layer Stack (4-layer recommended)
```
Layer 1 (Top):     Signal + components
Layer 2 (Inner 1): Ground plane (solid pour)
Layer 3 (Inner 2): Power planes (split: 25V zone, 12V zone, 5V zone)
Layer 4 (Bottom):  Signal + connectors
```

## PCB Design Rules
```
Min trace width:   0.2mm (signal), 2mm (5V/12V), 4mm (25V/motor), 6mm (battery)
Min clearance:     0.2mm (signal), 0.5mm (power to signal)
Via size:          0.6mm drill, 1.0mm pad (signal), 1.2mm drill, 2.0mm pad (power)
Thermal relief:    Required on all power plane connections
Copper pour:       Ground on all layers in unused areas
Motor driver:      Keep motor current loop tight (VM cap to IC to motor connector)
IMU:               Pour ground island under chip, single via to main ground
Crystal:           No traces under crystal, ground guard ring
CAN traces:        Differential pair, 120Ω impedance, equal length
```

---

## Next Steps
1. [ ] Create schematic in KiCad/Flux — start with power section
2. [ ] Assign footprints to all components
3. [ ] Define board outline (size TBD based on robot chassis)
4. [ ] Place components — MCU center, power edge, connectors perimeter
5. [ ] Route power planes first, then signals
6. [ ] DRC check
7. [ ] Gerber export → JLCPCB quote

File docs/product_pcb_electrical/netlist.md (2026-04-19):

# RECLAIM Product PCB — Complete Netlist
**Date:** March 25, 2026
**Revision:** 1.0
**Format:** Human-readable per-net listing for schematic entry in KiCad / Flux

---

## Net Naming Conventions

| Net Name | Voltage | Description |
|---|---|---|
| VBAT | 25.6V | Battery positive — split at source into two paths |
| VBAT_MOTOR | 25.6V | Motor/arm path: VBAT → F1 → Relay K1 COM |
| VBAT_COMPUTE  | 25.6V | Compute path: VBAT → F4 → U1 buck (always on) |
| VBAT_COIL | 25.6V | Relay coil path: VBAT → F5 → SW1(mushroom) → Q1 |
| GND | 0V | Common ground |
| VCC_25V | 25.6V | Post-relay motor bus (K1 NO contact output) |
| VCC_12V | 12V | After 25V→12V buck (U1) |
| VCC_5V | 5V | After 12V→5V buck (U2) |
| VCC_3V3 | 3.3V | After 5V→3.3V LDO (U3) |

### CRITICAL: Power Architecture Split

The VBAT line is split at the battery terminal into THREE independent paths:

1. **VBAT_MOTOR** → F1(30A) → Relay K1 COM → K1 NO → VCC_25V motor bus
   - Motors + arm only; cut by relay on software stop
2. **VBAT_COMPUTE** → F4(5A) → U1 25V→12V buck → always on
   - Jetson + STM32 + LiDAR; never cut by relay; powered at all times
3. **VBAT_COIL** → F5(2A) → SW1(mushroom NC) → Q1 Drain → K1 Coil → GND
   - Low-current coil circuit; mushroom opens this → relay de-energizes → motors cut

This solves the chicken-and-egg problem: the 12V compute rail comes from VBAT_COMPUTE
directly (pre-relay), so the STM32 and Q1 are powered before the relay closes.
The relay coil (24V Omron G5LE) is driven directly from VBAT_COIL (25.6V, within coil spec).

---

## Section 1 — Power Input & Distribution

### Net: VBAT
- J_BATTERY Pin 1 (battery positive terminal)
- F1 Pin 1 (30A motor/arm fuse input)
- F4 Pin 1 (5A compute fuse input) ← always-on compute path
- F5 Pin 1 (2A relay coil fuse input) ← always-on coil path

### Net: VBAT_MOTOR (post F1, pre-relay)
- F1 Pin 2
- K1 COM contact (relay input)

### Net: VBAT_COMPUTE (always on, post F4)
- F4 Pin 2
- U1 VIN (25V→12V buck for Jetson/LiDAR) ← compute always powered

### Net: VBAT_COIL (always on, post F5, through mushroom)
- F5 Pin 2
- SW1 Pin 1 (mushroom switch input — NC contact)
- SW1 Pin 2 → RELAY_COIL_IN

### Net: RELAY_COIL_IN (post mushroom, to Q1)
- SW1 Pin 2 (mushroom output)
- Q1 Drain (MOSFET pulls coil current to GND through coil)
- K1 Coil+ (relay coil positive terminal; 24V coil, powered from ~25.6V VBAT_COIL)
- D2 Cathode (flyback diode cathode)

### Net: VCC_25V (post-relay — motor bus, switched)
- K1 NO contact (Normally Open — CLOSES when relay energized = normal operation)
- F2L Pin 1 (15A left motor fuse input)
- F2R Pin 1 (15A right motor fuse input)
- F3 Pin 1 (10A arm fuse input)
- C1 Pin + (bulk cap positive)
- R6 Pin 1 (INA226 #1 shunt high side — 25V rail monitor)

**E-Stop Logic (CORRECTED):**
- Normal: PC8 HIGH → Q1 ON → coil energized → K1 NO closes → VCC_25V live → motors powered
- Software stop: PC8 LOW → Q1 OFF → coil de-energizes → NO opens → VCC_25V dead → motors cut
- Hardware E-stop: mushroom pressed → SW1 opens → coil loses power → NO opens → motors cut
- Fail-safe: any STM32 crash/power loss → Q1 OFF → relay drops → motors cut automatically

### Net: GND
- J_BATTERY Pin 2 (battery negative)
- K1 Coil− (relay coil return)
- D2 Anode (flyback diode anode)
- Q1 Source
- C1 Pin − through all bulk/decoupling caps
- U1, U2, U3 GND
- U4 VSS (all VSS pins), U4 VSSA
- U5L GND, U5R GND (all GND pins)
- U6A GND, U6S GND
- U7 GND
- U8 GND, U9 GND, U10 GND (INA226 ×3)
- U11 GND
- J_SWD Pin 4
- J_JETSON Pin 4
- J_LIDAR Pin 2
- J_CAN_ARM Pin 3
- J_MOTOR_L Pin 3, J_MOTOR_R Pin 3
- J_ENC_L Pin 4, J_ENC_R Pin 4
- J_LED_STATUS Pin 2
- J_BUMPER_FL/FR/RL/RR Pin 2
- All decoupling cap negative pins

### Net: MOTOR_PWR_L (left motor, post F2L)
- F2L Pin 2 (20A — updated from 15A for 42PG-775-92 motors, 5A rated / 24.5A stall, DRV8243 OCP handles stall)
- U5L VM (all VM pins)
- C12L Pin + (bulk cap)
- TVS1L Cathode

### Net: MOTOR_PWR_R (right motor, post F2R — SEPARATE from L)
- F2R Pin 2 (20A — updated from 15A for 42PG-775-92)
- U5R VM (all VM pins)
- C12R Pin +
- TVS1R Cathode

### Net: ARM_PWR (arm CAN power, post F3)
- F3 Pin 2
- J_CAN_ARM Pin 1 (optional power — CubeMars joints self-powered via separate harness)

### Net: VCC_12V
- U1 VOUT (25V→12V buck output — from always-on compute path)
- C2 Pin + (bulk cap)
- C5 Pin + (decoupling)
- U2 VIN (12V→5V buck)
- J_LIDAR Pin 1 (12V to Livox Mid-360, 8W)
- J_JETSON Pin 3 (12V to Jetson Orin NX, 25W)
- U11 VIN (PT4115 work light driver)
- R7 Pin 1 (INA226 #2 shunt high side)

### Net: VCC_12V_AFTER_SHUNT
- R7 Pin 2
- U9 IN+ (INA226 #2)

### Net: VCC_5V
- U2 VOUT
- C3 Pin +
- C6 Pin +
- U3 VIN (5V→3.3V LDO)
- J_LED_STATUS Pin 1 (5V to WS2812B ring)
- C20 Pin + (WS2812B bulk cap)
- J_CAMERA Pin 1 (5V USB power for OAK-D Pro)
- R8 Pin 1 (INA226 #3 shunt high side)

### Net: VCC_5V_AFTER_SHUNT
- R8 Pin 2
- U10 IN+ (INA226 #3)

### Net: VCC_3V3
- U3 VOUT
- C4 Pin +
- C7 Pin +
- U4 VDD (all 11 VDD pins — one 100nF cap each)
- U4 VDDA (analog supply)
- U4 VCAP1 → C_VCAP1 (1uF to GND) ← REQUIRED for internal regulator
- U4 VCAP2 → C_VCAP2 (1uF to GND) ← REQUIRED for internal regulator
- U5L VCC, U5R VCC (DRV8243 logic supply)
- U6A VCC, U6S VCC (CAN transceivers)
- U7 VDD, U7 VDDIO (ICM-42688-P)
- U8 VS, U9 VS, U10 VS (INA226 logic supply)
- J_SWD Pin 3 (ST-Link VCC reference)
- J_ENC_L Pin 3, J_ENC_R Pin 3 (encoder 3.3V supply)
- R_I2C_SCL Pin 1 (pull-up resistor to VCC_3V3)
- R_I2C_SDA Pin 1
- U9 A0 (INA226 #2 address pin 0 = HIGH = VCC_3V3 → addr 0x41)
- U10 A1 (INA226 #3 address pin 1 = HIGH = VCC_3V3 → addr 0x44)

---

## Section 2 — STM32F405 MCU Connections

### STM32 to SPI1 Bus (shared)
- Net: SPI1_SCK  → U4 PA5, U5L SCLK, U5R SCLK, U7 SCLK
- Net: SPI1_MISO → U4 PA6, U5L SDO, U5R SDO, U7 SDO
- Net: SPI1_MOSI → U4 PA7, U5L SDI, U5R SDI, U7 SDI
- Net: SPI1_CS_DRV_L → U4 PB0, U5L CS (active low)
- Net: SPI1_CS_DRV_R → U4 PB1, U5R CS (active low)
- Net: SPI1_CS_IMU   → U4 PB2, U7 CS (active low)

### STM32 to CAN Bus
- Net: CAN1_RX → U4 PB8, U6A RXD
- Net: CAN1_TX → U4 PB9, U6A TXD
- Net: CAN2_RX → U4 PB12, U6S RXD
- Net: CAN2_TX → U4 PB13, U6S TXD
- Net: CAN_H_ARM → U6A CANH, J_CAN_ARM Pin 1, R4A Pin 1
- Net: CAN_L_ARM → U6A CANL, J_CAN_ARM Pin 2, R4A Pin 2
- Net: CAN_H_SPARE → U6S CANH, R4S Pin 1 (loop back or expose on connector)
- Net: CAN_L_SPARE → U6S CANL, R4S Pin 2

### STM32 to USART2 (Jetson micro-ROS)
- Net: USART2_TX → U4 PA2, U_USB TX_IN (CP2102N)
- Net: USART2_RX → U4 PA3, U_USB RX_OUT
- Net: USB_D+ → U_USB D+, J3 D+
- Net: USB_D− → U_USB D−, J3 D−

### STM32 to Encoder Timers
- Net: ENC_L_A → U4 PA0 (TIM2_CH1), J_ENC_L Pin 1   ← TIM2 is 32-bit, better for high tick counts
- Net: ENC_L_B → U4 PA1 (TIM2_CH2), J_ENC_L Pin 2
- Net: ENC_R_A → U4 PB4 (TIM3_CH1), J_ENC_R Pin 1
- Net: ENC_R_B → U4 PB5 (TIM3_CH2), J_ENC_R Pin 2

### STM32 to I2C1 (INA226 power monitors)
- Net: I2C1_SCL → U4 PB6, U8 SCL, U9 SCL, U10 SCL, R_I2C_SCL Pin 2 (pull-up to VCC_3V3)
- Net: I2C1_SDA → U4 PB7, U8 SDA, U9 SDA, U10 SDA, R_I2C_SDA Pin 2 (pull-up to VCC_3V3)
Note: Both SCL and SDA need 4.7kΩ pull-ups to VCC_3V3 (R_I2C_SCL and R_I2C_SDA). Without these the I2C bus will not work.

### STM32 GPIO
- Net: WS2812_DATA → U4 PC6 (TIM8_CH1), R9 Pin 1
  - R9 Pin 2 → J_LED_STATUS Pin 3 (data to LED ring)
- Net: WORK_LIGHT_PWM → U4 PC7 (TIM8_CH2), U11 PWM_DIM (PT4115)
- Net: ESTOP_RELAY_CTRL → U4 PC8, R11 Pin 1
  - R11 Pin 2 → Q1 Gate
- Net: BUMPER_FL → U4 PC9 (internal pull-up), J_BUMPER_FL Pin 1
- Net: BUMPER_FR → U4 PC10, J_BUMPER_FR Pin 1
- Net: BUMPER_RL → U4 PC11, J_BUMPER_RL Pin 1
- Net: BUMPER_RR → U4 PC12, J_BUMPER_RR Pin 1

### STM32 SWD Debug
- Net: SWDIO → U4 PA13, J2 Pin 1, J_SWD Pin 1
- Net: SWDCK → U4 PA14, J2 Pin 2, J_SWD Pin 2
- Net: MCU_NRST → U4 NRST, R1 Pin 1, C (100nF to GND)
  - R1 Pin 2 → VCC_3V3

### STM32 VCAP (REQUIRED — internal voltage regulator)
- Net: VCAP1 → U4 VCAP1, C_VCAP1 Pin + (1uF to GND)
- Net: VCAP2 → U4 VCAP2, C_VCAP2 Pin + (1uF to GND)
NOTE: Without VCAP caps the STM32 will fail to start. These are mandatory per datasheet.

### STM32 NRST Filter
- Net: MCU_NRST → U4 NRST, R1 Pin 1, C_NRST Pin + (100nF to GND)
  - R1 Pin 2 → VCC_3V3

### STM32 BOOT0
- Net: BOOT0 → U4 BOOT0, R2 Pin 1
  - R2 Pin 2 → GND (normal boot; add 2-pin jumper header to allow DFU mode override)

---

## Section 3 — Motor Drivers (DRV8243)

### Left Motor Driver (U5L) — Full Net List
- U5L VM → MOTOR_PWR_L
- U5L VCC → VCC_3V3
- U5L GND → GND
- U5L SCLK → SPI1_SCK
- U5L SDI → SPI1_MOSI
- U5L SDO → SPI1_MISO
- U5L CS → SPI1_CS_DRV_L (PB0)
- U5L FAULTZ → Net: DRV_FAULT_L → U4 GPIO (choose free pin, e.g. PB14)
- U5L OUT1 → J_MOTOR_L Pin 1 (motor terminal A)
- U5L OUT2 → J_MOTOR_L Pin 2 (motor terminal B)
- U5L ISENSE → R3L Pin 1 (sense resistor)
  - R3L Pin 2 → GND (shunt to GND)
  - ISENSE net → U4 ADC input (e.g. PC0 = ADC10)

### Right Motor Driver (U5R) — Full Net List
- U5R VM → MOTOR_PWR_R
- U5R VCC → VCC_3V3
- U5R GND → GND
- U5R SCLK → SPI1_SCK
- U5R SDI → SPI1_MOSI
- U5R SDO → SPI1_MISO
- U5R CS → SPI1_CS_DRV_R (PB1)
- U5R FAULTZ → Net: DRV_FAULT_R → U4 GPIO (e.g. PB15)
- U5R OUT1 → J_MOTOR_R Pin 1
- U5R OUT2 → J_MOTOR_R Pin 2
- U5R ISENSE → R3R Pin 1
  - R3R Pin 2 → GND
  - ISENSE net → U4 ADC input (e.g. PC1 = ADC11)

### TVS Diode Connections
- TVS1L Anode → GND
- TVS1L Cathode → MOTOR_PWR_L (clamp at 28V)
- TVS1R Anode → GND
- TVS1R Cathode → MOTOR_PWR_R

---

## Section 4 — CAN Bus Interface

### Arm CAN (U6A)
- U6A VCC → VCC_3V3
- U6A GND → GND
- U6A TXD → CAN1_TX (PB9)
- U6A RXD → CAN1_RX (PB8)
- U6A CANH → CAN_H_ARM
- U6A CANL → CAN_L_ARM
- U6A RS → GND (high speed mode; RS pin must be tied to GND)
- C14A: VCC_3V3 to GND (decoupling, placed immediately at IC)

### Spare CAN (U6S)
- U6S VCC → VCC_3V3
- U6S GND → GND
- U6S TXD → CAN2_TX (PB13)
- U6S RXD → CAN2_RX (PB12)
- U6S CANH → CAN_H_SPARE
- U6S CANL → CAN_L_SPARE
- U6S RS → GND
- C14S: VCC_3V3 to GND

### Termination Resistors
- R4A: CAN_H_ARM to CAN_L_ARM (120Ω, board end termination)
- R4S: CAN_H_SPARE to CAN_L_SPARE (120Ω)

---

## Section 5 — IMU (ICM-42688-P)

- U7 VDD → VCC_3V3
- U7 GND → GND
- U7 VDDIO → VCC_3V3
- U7 SCLK → SPI1_SCK
- U7 SDI → SPI1_MOSI
- U7 SDO → SPI1_MISO
- U7 CS → SPI1_CS_IMU (PB2)
- U7 INT1 → R5 Pin 1 (DNP; optional interrupt)
  - R5 Pin 2 → VCC_3V3 (DNP)
- C15: VDD to GND (100nF, place <0.5mm from IC)
- C16: VDD to GND (1uF bulk)

---

## Section 6 — Power Monitoring (INA226 ×3)

### INA226 #1 — 25V Bus Monitor (U8, addr 0x40)
- U8 VBS → VCC_25V (before shunt, bus voltage reference)
- U8 IN+ → VCC_25V (shunt high side)
- U8 IN− → Net: VCC_25V_AFTER_SHUNT → R6 Pin 2 (shunt low side)
- R6 Pin 1 → VCC_25V
- U8 VS → VCC_3V3 (logic supply)
- U8 GND → GND
- U8 SCL → I2C1_SCL (PB6)
- U8 SDA → I2C1_SDA (PB7)
- U8 A0 → GND (addr bit 0 = 0)
- U8 A1 → GND (addr bit 1 = 0) → 0x40
- C17: VS to GND (decoupling)

### INA226 #2 — 12V Bus Monitor (U9, addr 0x41)
- U9 IN+ → VCC_12V (shunt high side)
- U9 IN− → VCC_12V_AFTER_SHUNT → downstream 12V loads
- R7: VCC_12V to VCC_12V_AFTER_SHUNT
- U9 VS → VCC_3V3
- U9 GND → GND
- U9 SCL → I2C1_SCL
- U9 SDA → I2C1_SDA
- U9 A0 → VCC_3V3 (addr bit 0 = 1)
- U9 A1 → GND (addr bit 1 = 0) → 0x41
- C18: VS to GND

### INA226 #3 — 5V Bus Monitor (U10, addr 0x44)
- U10 IN+ → VCC_5V (shunt high side)
- U10 IN− → VCC_5V_AFTER_SHUNT
- R8: VCC_5V to VCC_5V_AFTER_SHUNT
- U10 VS → VCC_3V3
- U10 GND → GND
- U10 SCL → I2C1_SCL
- U10 SDA → I2C1_SDA
- U10 A0 → GND (addr bit 0 = 0)
- U10 A1 → VCC_3V3 (addr bit 1 = 1) → 0x44
- C19: VS to GND

---

## Section 7 — Status LED & Work Light

### WS2812B LED Ring
- J_LED_STATUS Pin 1 → VCC_5V
- J_LED_STATUS Pin 2 → GND
- J_LED_STATUS Pin 3 (DATA) → R9 Pin 2
  - R9 Pin 1 → WS2812_DATA (PC6)
- C20: VCC_5V to GND (100uF, place near J_LED_STATUS)

### Work Light (Cree XHP35 via PT4115)
- U11 VIN → VCC_12V (PT4115 powered from 12V always-on compute rail)
- U11 GND → GND
- U11 SW → L_LED Pin 1 (switching node)   ← inductor renamed L_LED to avoid conflict with buck inductors
  - L_LED Pin 2 → J_LED_WORK Pin 1 (LED anode)
- D_LED Anode → GND
- D_LED Cathode → L_LED Pin 2 (freewheel diode on switching node output)
- J_LED_WORK Pin 2 (LED cathode) → R10 Pin 1 (current sense)
  - R10 Pin 2 → GND
- U11 CS → R10 Pin 1 (current sense feedback to PT4115)
- U11 DIM → WORK_LIGHT_PWM (PC7)

---

## Section 8 — Safety & E-Stop

### E-Stop Relay Circuit (CORRECTED — uses NO contact, fail-safe design)
- K1 COM → VBAT_MOTOR (post F1 motor fuse)
- K1 NO → VCC_25V (NO = Normally Open; CLOSES only when coil energized = motors powered)
- K1 Coil+ → RELAY_COIL_IN (comes from SW1 mushroom output)
- K1 Coil− → GND
- D2 Cathode → RELAY_COIL_IN (flyback: absorbs coil energy when Q1 turns off)
- D2 Anode → GND
- Q1 Drain → RELAY_COIL_IN (Q1 completes coil circuit to GND)
- Q1 Gate → R11 Pin 2 (R11 Pin 1 → ESTOP_RELAY_CTRL = PC8)
- Q1 Source → GND
- R12 Gate-to-GND pull-down (47kΩ): Q1 Gate to GND — ensures OFF at power-up before STM32 boots

### E-Stop Logic (FAIL-SAFE — power requires active energization)
- Power ON: PC8 HIGH → Q1 ON → K1 coil energized → NO closes → motors powered
- Software stop: PC8 LOW → Q1 OFF → coil lost → NO opens → motors cut
- Hardware E-stop: mushroom pressed → SW1 opens → coil current path broken → NO opens → cut
- STM32 crash or brown-out: PC8 floats/LOW → Q1 OFF → relay drops → motors cut (FAIL-SAFE)
- Battery disconnect: all rails lost → coil lost → motors cut

### Bumper Switches (NO microswitches — triggered = LOW)
- J_BUMPER_FL Pin 1 → BUMPER_FL → U4 PA0 ... wait, PA0 is ENC_L. Use PC9.
  - Correct: J_BUMPER_FL Pin 1 → BUMPER_FL → U4 PC9 (internal pull-up enabled in firmware)
- J_BUMPER_FL Pin 2 → GND
- J_BUMPER_FR → PC10, J_BUMPER_RL → PC11, J_BUMPER_RR → PC12
- In firmware: enable STM32 internal pull-ups on PC9-PC12. Normal = HIGH. Bumper hit = LOW (switch closes to GND)

### Bumper Switches
- J_BUMPER_FL Pin 1 → BUMPER_FL → U4 PC9 (with internal pull-up)
- J_BUMPER_FL Pin 2 → GND
- J_BUMPER_FR Pin 1 → BUMPER_FR → U4 PC10
- J_BUMPER_FR Pin 2 → GND
- J_BUMPER_RL Pin 1 → BUMPER_RL → U4 PC11
- J_BUMPER_RL Pin 2 → GND
- J_BUMPER_RR Pin 1 → BUMPER_RR → U4 PC12
- J_BUMPER_RR Pin 2 → GND

---

## Section 9 — External Connectors Summary

| Connector | Pin 1 | Pin 2 | Pin 3 | Pin 4 |
|---|---|---|---|---|
| J_BATTERY | VBAT+ | GND | - | - |
| J_JETSON | USART2_TX | USART2_RX | VCC_5V or VCC_12V | GND |
| J_LIDAR | VCC_12V | GND | ETH_TX+ | ETH_TX− |
| J_CAMERA | VCC_5V | GND | - | - |
| J_CAN_ARM | CAN_H_ARM | CAN_L_ARM | GND | - |
| J_MOTOR_L | OUT1_L | OUT2_L | GND | - |
| J_MOTOR_R | OUT1_R | OUT2_R | GND | - |
| J_ENC_L | ENC_L_A | ENC_L_B | VCC_3V3 | GND |
| J_ENC_R | ENC_R_A | ENC_R_B | VCC_3V3 | GND |
| J_LED_STATUS | VCC_5V | GND | WS2812_DATA | - |
| J_LED_WORK | LED_ANODE | LED_CATHODE | - | - |
| J_ESTOP | VBAT_IN | VBAT_SWITCHED | - | - |
| J_BUMPER_FL | BUMPER_FL | GND | - | - |
| J_BUMPER_FR | BUMPER_FR | GND | - | - |
| J_BUMPER_RL | BUMPER_RL | GND | - | - |
| J_BUMPER_RR | BUMPER_RR | GND | - | - |
| J_SWD | SWDIO | SWDCK | VCC_3V3 | GND |

---

## I2C Address Summary

| Device | A1 | A0 | Address |
|---|----|----|---|
| INA226 #1 (25V bus) | GND | GND | 0x40 |
| INA226 #2 (12V bus) | GND | VCC | 0x41 |
| INA226 #3 (5V bus) | VCC | GND | 0x44 |

---

## STM32F405 Pin Assignment Summary (LQFP-64)

| STM32 Pin | Net Name | Function | Direction |
|---|---|---|---|
| PA2 | USART2_TX | micro-ROS to Jetson | OUT |
| PA3 | USART2_RX | micro-ROS from Jetson | IN |
| PA5 | SPI1_SCK | Shared SPI clock | OUT |
| PA6 | SPI1_MISO | SPI data in | IN |
| PA7 | SPI1_MOSI | SPI data out | OUT |
| PA0 | ENC_L_A | Left encoder A (TIM2_CH1) — 32-bit timer | IN |
| PA1 | ENC_L_B | Left encoder B (TIM2_CH2) | IN |
| PA13 | SWDIO | SWD debug | IO |
| PA14 | SWDCK | SWD clock | IN |
| PB0 | SPI1_CS_DRV_L | DRV8243 Left chip select | OUT |
| PB1 | SPI1_CS_DRV_R | DRV8243 Right chip select | OUT |
| PB2 | SPI1_CS_IMU | ICM-42688-P chip select | OUT |
| PB4 | ENC_R_A | Right encoder A (TIM3_CH1) | IN |
| PB5 | ENC_R_B | Right encoder B (TIM3_CH2) | IN |
| PB6 | I2C1_SCL | INA226 clock | OUT |
| PB7 | I2C1_SDA | INA226 data | IO |
| PB8 | CAN1_RX | Arm CAN receive | IN |
| PB9 | CAN1_TX | Arm CAN transmit | OUT |
| PB12 | CAN2_RX | Spare CAN receive | IN |
| PB13 | CAN2_TX | Spare CAN transmit | OUT |
| PB14 | DRV_FAULT_L | DRV8243 Left fault (active low) | IN |
| PB15 | DRV_FAULT_R | DRV8243 Right fault (active low) | IN |
| PC0 | ADC_ISENSE_L | Left motor current sense (ADC10) | AIN |
| PC1 | ADC_ISENSE_R | Right motor current sense (ADC11) | AIN |
| PC6 | WS2812_DATA | LED ring data (TIM8_CH1 PWM) | OUT |
| PC7 | WORK_LIGHT_PWM | PT4115 dimming (TIM8_CH2 PWM) | OUT |
| PC8 | ESTOP_RELAY_CTRL | Relay control via MOSFET | OUT |
| PC9 | BUMPER_FL | Front-left bumper (pull-up) | IN |
| PC10 | BUMPER_FR | Front-right bumper (pull-up) | IN |
| PC11 | BUMPER_RL | Rear-left bumper (pull-up) | IN |
| PC12 | BUMPER_RR | Rear-right bumper (pull-up) | IN |

---

## Critical Layout Notes

1. **Motor current loop** — Place C12L/C12R (10uF VM bulk) and TVS1L/TVS1R within 5mm of U5L/U5R VM pins. Route VM → cap → TVS → motor output in a tight loop.

2. **IMU isolation** — Pour a ground island (solid copper) directly under U7 on Layer 2. Single via to main ground plane. Keep >5mm from motor driver switching nodes.

3. **Crystal guard** — No signal traces under Y1. Add a ground guard ring around crystal and load caps C9/C10.

4. **CAN differential pair** — Route CAN_H and CAN_L as a matched-length differential pair. Aim for 120Ω differential impedance (use 0.2mm trace, 0.2mm gap on 4-layer). Equal length to within 0.5mm.

5. **Decoupling placement** — All 100nF decoupling caps must be within 1mm of the IC supply pin they decouple. STM32 has 11 VDD pins — each needs its own 100nF cap.

6. **Ground copper pour** — Fill all unused space on all layers with GND copper. Stitch vias every 5mm between layers.

7. **Power trace widths** (IPC-2221 for 25°C rise):
   - VBAT / VCC_25V motor branch: min 4mm (carries up to 15A motors + 10A arm)
   - VCC_12V: min 2mm (10A max)
   - VCC_5V: min 1mm (3A max)
   - VCC_3V3: min 0.5mm (500mA max)
   - Signal traces: 0.2mm minimum

8. **E-stop relay** — Keep K1 away from MCU and IMU. Relay switching creates magnetic field. Minimum 20mm clearance from U4 and U7.

9. **Connector placement** — All external connectors on PCB perimeter. Battery connector top-edge center. Motor connectors bottom. CAN arm connector side-edge.

10. **Thermal** — U1 and U2 bucks need thermal vias under exposed pad to inner copper pour. PT4115 U11 similarly needs thermal relief (but Cree LED is off-board on chassis).

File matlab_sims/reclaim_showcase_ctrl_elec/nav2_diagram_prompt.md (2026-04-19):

# Nav2 Product Control Architecture — Diagram Prompt
# Send this to Claude to generate the product controls visual

---

## PROMPT

Create a clean, professional vertical control architecture diagram for a capstone engineering
presentation slide. This is for RECLAIM — an autonomous indoor waste collection robot.

The diagram must visually match a Simulink block diagram aesthetic — clean rectangular boxes,
simple directional arrows, minimal decoration, engineering-style labels. No gradients, no 3D
effects, no icons.

---

## COLOUR PALETTE (use exactly these hex values)

Software layers:  fill #EFF6FF (very light blue),  border #2563EB (blue),  2px solid
Hardware layers:  fill #F3F4F6 (light grey),        border #374151 (dark grey), 2px solid
Arm sidebar:      fill #FFFBEB (light amber),        border #D97706 (amber),    2px dashed
Signal arrows:    colour #374151 (dark grey), 1.5px, small filled arrowhead
Signal labels:    colour #16A34A (dark green), italic, 9pt, beside each arrow
Background:       white #FFFFFF
Font:             Helvetica or Arial throughout (matches Simulink default font)

---

## DIAGRAM CONTENT

Title above diagram (bold, 13pt, #1a1a2e):
"RECLAIM PRODUCT — Nav2 Autonomy Stack"

LAYERS — stacked vertically, each box 580px wide, 85px tall, 6px rounded corners:

BOX 1 — SOFTWARE — blue fill/border:
  Title (bold 11pt): "Behaviour Tree  |  ROS2 Nav2"
  Body (10pt): "Mission orchestration: Navigate → Detect → Pick → Sort → Repeat"

  ↓ arrow, label: "goal pose  (x, y, θ)"

BOX 2 — SOFTWARE — blue fill/border:
  Title (bold 11pt): "SLAM Toolbox  +  Livox Mid-360 3D LiDAR"
  Body (10pt): "Occupancy grid mapping  |  Particle filter localisation"

  ↓ arrow, label: "costmap  +  robot pose"

BOX 3 — SOFTWARE — blue fill/border:
  Title (bold 11pt): "Global Planner  (Smac / A*)"
  Body (10pt): "Static layer  |  Obstacle layer  |  Inflation layer (robot footprint)"

  ↓ arrow, label: "reference path"

BOX 4 — SOFTWARE — blue fill/border:
  Title (bold 11pt): "Local Controller  —  Regulated Pure Pursuit"
  Body (10pt): "Lookahead distance  |  Curvature limiting  |  Velocity scaling near obstacles"

  ↓ arrow, label: "cmd_vel  (geometry_msgs/Twist)"

BOX 5 — HARDWARE — grey fill/border:
  Title (bold 11pt): "STM32F405  |  PI Velocity Controller  @  1 kHz"
  Body (10pt): "Kp, Ki per wheel  |  Feed-forward Kf  |  DRV8243 motor drivers"

  ↓ arrow, label: "PWM  0–255"
  ↑ arrow (feedback, right side), label: "encoder ticks  @  100 Hz"

BOX 6 — HARDWARE — grey fill/border:
  Title (bold 11pt): "Pololu 37D  12V  100:1  +  Quadrature Encoders"
  Body (10pt): "64 CPR × 100:1 = 6400 ticks/rev  |  Odometry → /odom"

---

ARM SIDEBAR — amber fill/dashed border:
Position: to the RIGHT of boxes 4 and 5, vertically spanning same height, 160px wide

Content (10pt, top to bottom):
  ARM SUBSYSTEM
  ─────────────
  OAK-D Pro
  Eye-in-hand

  YOLOv8n
  30 fps TensorRT

  6DOF CubeMars
  Actuators

  CAN Bus 1 Mbit/s
  STM32 CAN1
  SN65HVD230

Dashed horizontal arrow FROM Box 4 TO sidebar top, label: "pick trigger"
Dashed horizontal arrow FROM sidebar bottom TO Box 5, label: "arm done"

---

LEGEND — bottom right, small (9pt):
  ■ blue = Software layer
  ■ grey = Hardware layer
  ■ amber dashed = Arm subsystem
  → solid = ROS2 topic / signal
  ⇢ dashed = subsystem trigger

---

## OUTPUT REQUIREMENTS

- Output as Python code using matplotlib that generates a high-resolution PNG (300 DPI)
- Save as: reclaim_product_nav2_diagram.png
- Total diagram size: 800px × 1000px at 96dpi (renders as ~8.3 × 10.4 inches at 96dpi)
- Do NOT use placeholder text — use exactly the layer content specified above
- All text must be fully readable at 100% zoom — no overlapping, no clipping
- Boxes must have consistent spacing: 20px gap between each layer box

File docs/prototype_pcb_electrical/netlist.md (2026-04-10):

# RECLAIM Prototype — Complete Netlist
**Date:** April 10, 2026
**Revision:** 1.0
**Format:** Human-readable per-net listing for schematic entry in KiCad

---

## Net Naming Conventions

| Net Name | Voltage | Description |
|---|---|---|
| VBAT | 12.8V | Battery positive terminal |
| GND | 0V | Common ground |
| VBAT_FUSED_1  | 12.8V | Post-fuse ch1 — XINGYHENG buck (5A) |
| VBAT_FUSED_2  | 12.8V | Post-fuse ch2 — Cytron MD13C R3 (10A) |
| VBAT_FUSED_3  | 12.8V | Post-fuse ch3 — MIC-711 IPC (10A) |
| VBAT_FUSED_4  | 12.8V | Post-fuse ch4 — BTS7960 (20A) |
| V_SERVO | 6.8V | Buck output — servo power rail |
| V_5V_USB | 5V | MIC-711 USB ports (powers router, Teensy) |

---

## Section 1 — Power Input & Distribution

### Net: VBAT
- Battery positive terminal
- DC Disconnect switch Pin 1 (input/battery side)

### Net: VBAT_SWITCHED
- DC Disconnect switch Pin 2 (load side)
- Fuse Block common bus (input)

### Net: VBAT_FUSED_1 (5A — servo buck)
- Fuse Block Ch1 output (5A blade fuse)
- U_BUCK VIN+ (XINGYHENG buck input positive)

### Net: VBAT_FUSED_2 (10A — left motor driver)
- Fuse Block Ch2 output (10A blade fuse)
- U_DRV_L Power+ (Cytron MD13C R3 motor power input)

### Net: VBAT_FUSED_3 (10A — MIC-711)
- Fuse Block Ch3 output (10A blade fuse)
- U_IPC VCC terminal (MIC-711 2-pin power connector positive)

### Net: VBAT_FUSED_4 (20A — right motor driver)
- Fuse Block Ch4 output (20A blade fuse)
- U_DRV_R B+ (BTS7960 motor power input)

### Net: GND
- Battery negative terminal
- DC Disconnect switch Pin 3 (ground passthrough, if used)
- Fuse Block common ground bus
- U_BUCK GND
- U_DRV_L GND
- U_DRV_R GND
- U_IPC GND terminal (MIC-711 2-pin power connector negative)
- Teensy GND pin
- All servo GND (via Wago GND rail)
- C_BULK negative
- Encoder GND pins (both motors)

---

## Section 2 — Servo Power Rail

### Net: V_SERVO (6.8V)
- U_BUCK VOUT+ (buck converter output positive)
- C_BULK positive (10,000µF bulk cap)
- Wago 221-415 #1 input (VCC distribution)
- → J1 servo VCC (DS3218 Base)
- → J2 servo VCC (DS3235 Shoulder)
- → J3 servo VCC (DS3218 Elbow)
- Wago 221-415 #2 input (VCC distribution)
- → J4 servo VCC (DS3218 Wrist Pitch)
- → J5 servo VCC (MG996R Wrist Rotate)
- → J6 servo VCC (DS3218 Gripper)

### Net: GND (servo return)
- U_BUCK VOUT− (buck converter output negative)
- C_BULK negative
- Wago 221-415 #3 input (GND distribution)
- → J1-J3 servo GND
- Wago 221-415 #4 input (GND distribution)
- → J4-J6 servo GND

---

## Section 3 — Motor Drivers & Motors

### Left Motor — Cytron MD13C R3

#### Net: MOTOR_L+
- U_DRV_L Motor A output
- M_L motor pin M1

#### Net: MOTOR_L−
- U_DRV_L Motor B output
- M_L motor pin M2

#### Net: PWM_L (Teensy pin 2)
- Teensy 4.1 Pin 2
- U_DRV_L PWM input

#### Net: DIR_L (Teensy pin 3)
- Teensy 4.1 Pin 3
- U_DRV_L DIR input

### Right Motor — BTS7960

#### Net: MOTOR_R+
- U_DRV_R Motor M+ output
- M_R motor pin M1

#### Net: MOTOR_R−
- U_DRV_R Motor M− output
- M_R motor pin M2

#### Net: LPWM_R (Teensy pin 23)
- Teensy 4.1 Pin 23
- U_DRV_R LPWM input

#### Net: RPWM_R (Teensy pin 22 — DIR pin repurposed)
- Teensy 4.1 Pin 22
- U_DRV_R RPWM input

#### Net: BTS_R_EN (3.3V enable)
- Teensy 4.1 3.3V pin
- U_DRV_R R_EN input

#### Net: BTS_L_EN (3.3V enable)
- Teensy 4.1 3.3V pin
- U_DRV_R L_EN input

Note: R_EN and L_EN tied directly to 3.3V (always enabled). Pin 20 does NOT support PWM on Teensy 4.1 — LPWM moved to pin 23.

---

## Section 4 — Encoders

### Left Encoder (JGB37-520)

#### Net: ENC_L_A (Teensy pin 6)
- Teensy 4.1 Pin 6
- M_L encoder output A

#### Net: ENC_L_B (Teensy pin 7)
- Teensy 4.1 Pin 7
- M_L encoder output B

#### Net: ENC_L_VCC (3.3V)
- Teensy 4.1 3V pin
- M_L encoder VCC

### Right Encoder (JGB37-520)

#### Net: ENC_R_A (Teensy pin 19)
- Teensy 4.1 Pin 19
- M_R encoder output A

#### Net: ENC_R_B (Teensy pin 18)
- Teensy 4.1 Pin 18
- M_R encoder output B
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

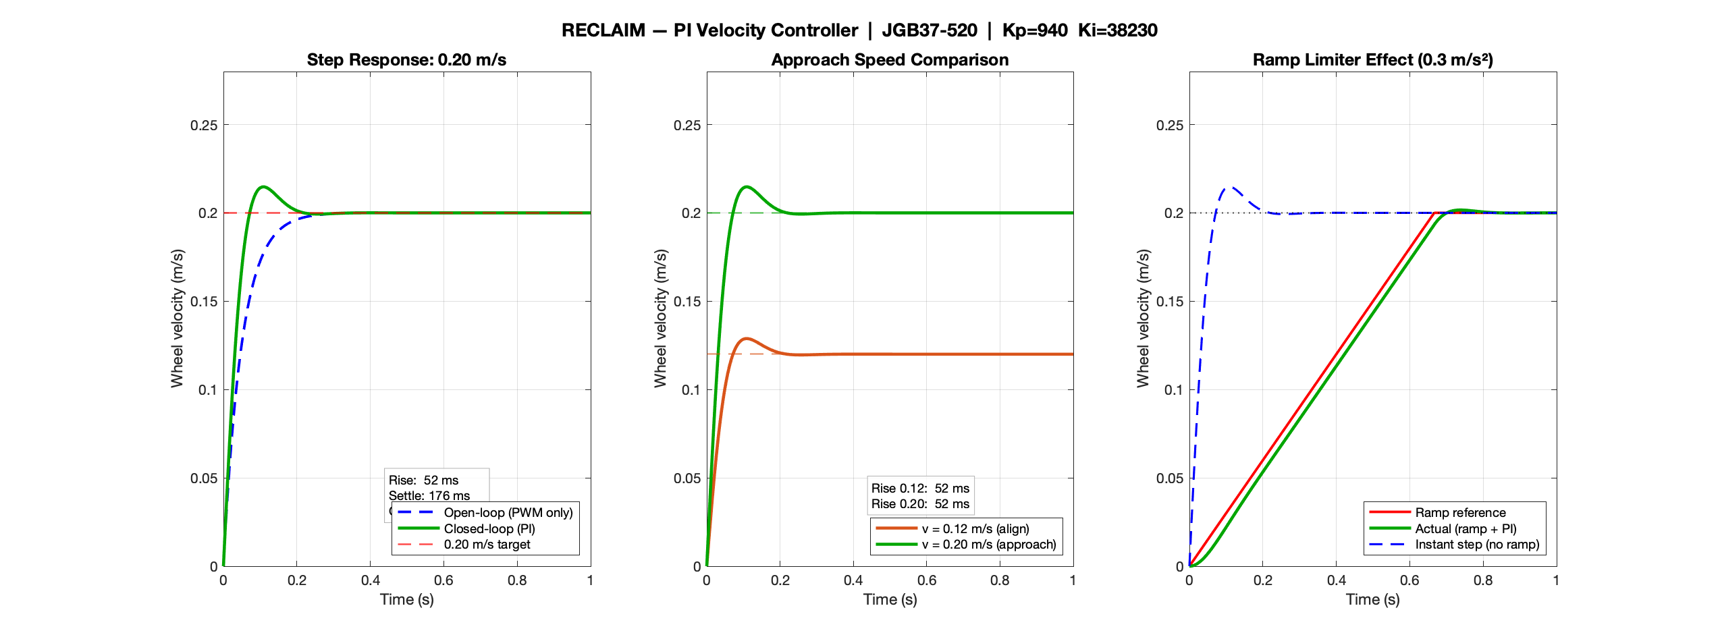
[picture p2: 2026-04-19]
docs/schematic_images/Simulink_DC_Motor_Model.png

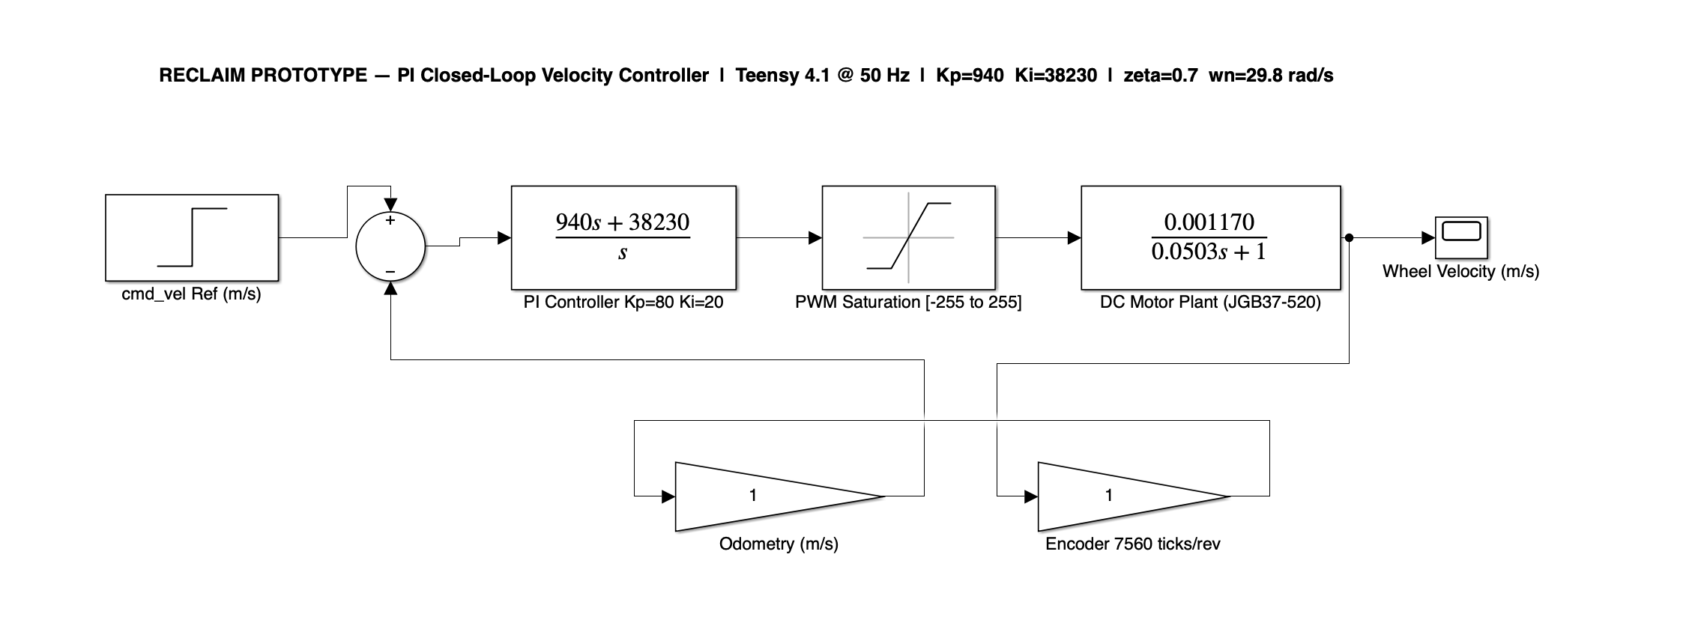
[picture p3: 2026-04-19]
docs/schematic_images/Simulink_Prototype_Controls.png

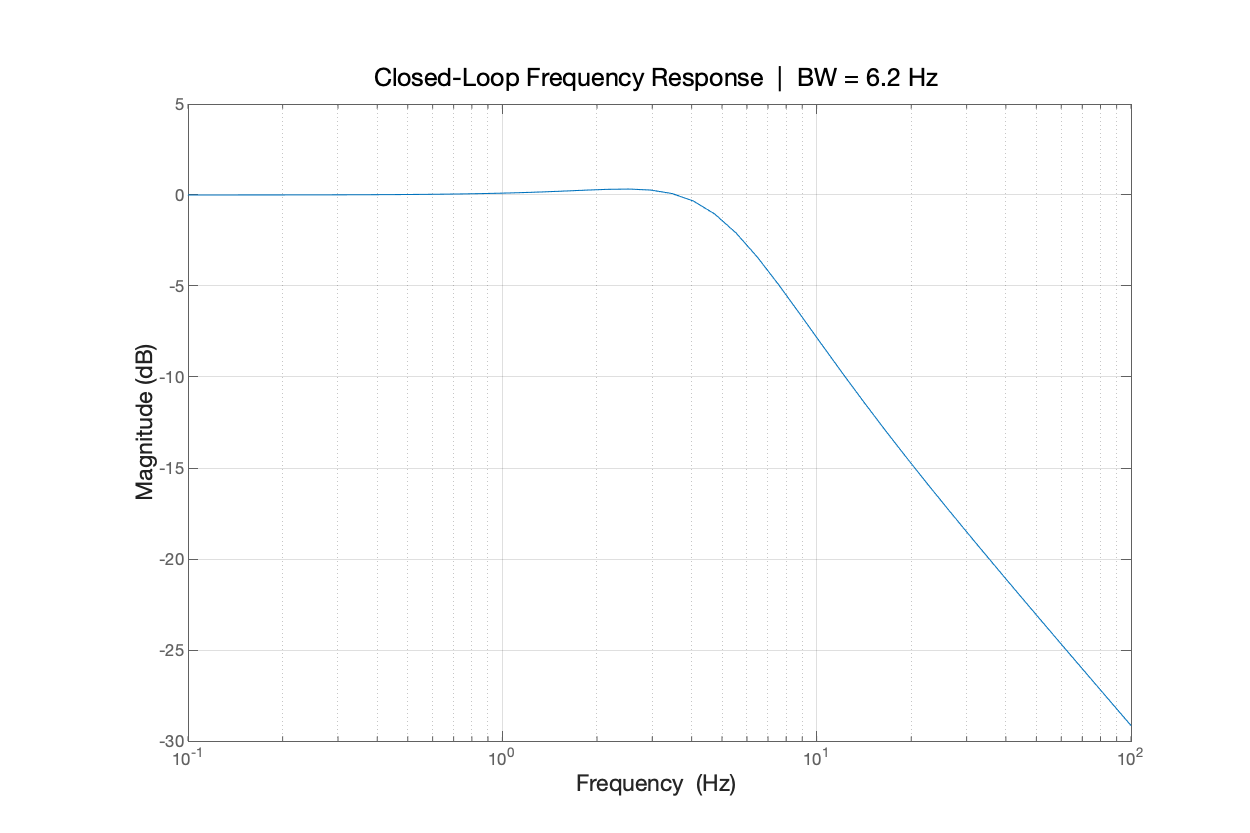
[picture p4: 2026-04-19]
docs/schematic_images/Simulink_Bode_Plot.png

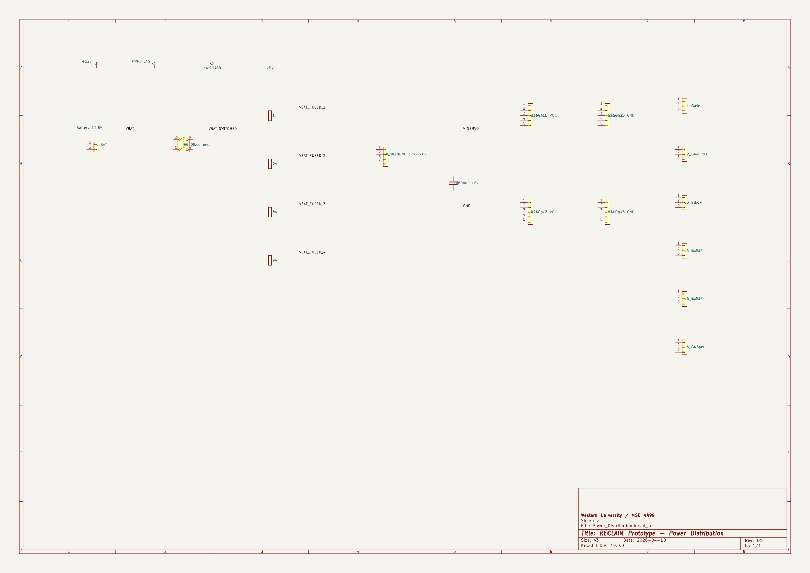
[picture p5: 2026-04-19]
docs/schematic_images/Prototype_Power_Distribution_preview.png

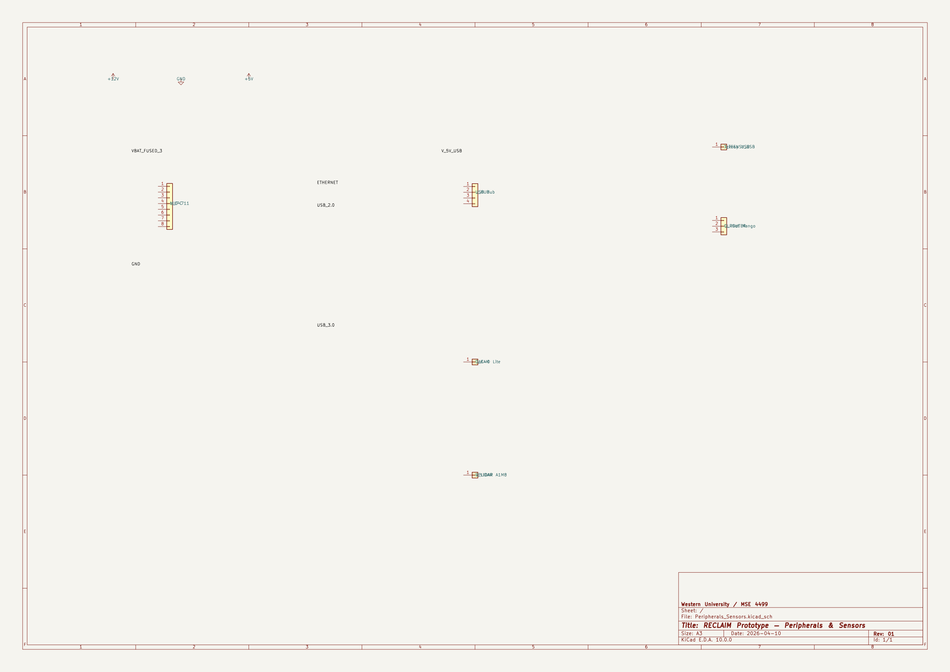
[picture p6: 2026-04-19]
docs/schematic_images/Prototype_Peripherals_Sensors_preview.png

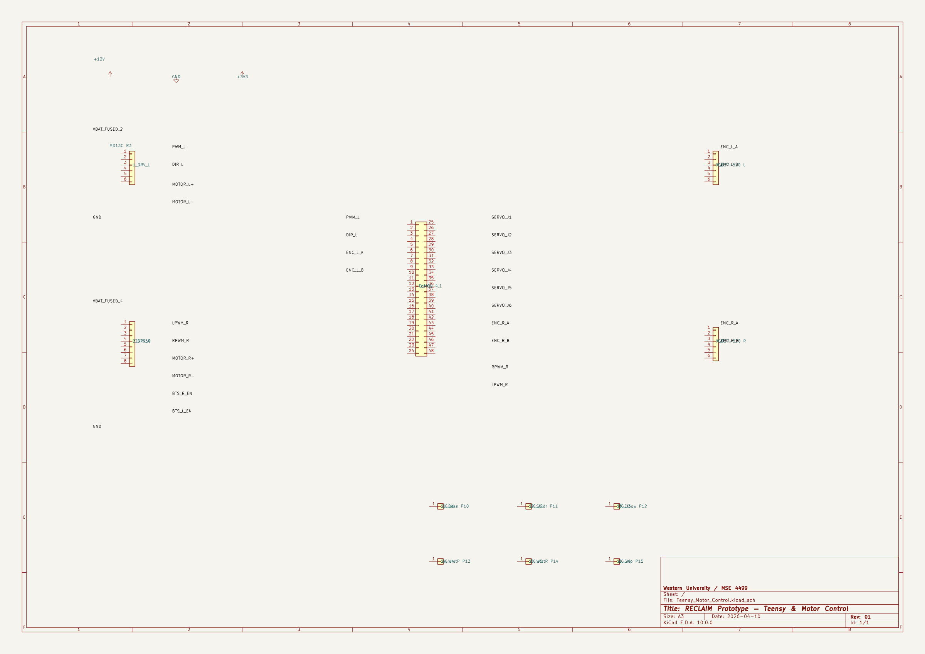
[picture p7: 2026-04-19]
docs/schematic_images/Prototype_Teensy_Motor_Control_preview.png

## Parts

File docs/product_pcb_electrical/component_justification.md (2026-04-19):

# RECLAIM Product — Component Selection & Justification
**Date:** March 25, 2026
**Status:** Finalized for PCB design phase

---

## Why No PCB for the Prototype

The short answer: **you don't know what you don't know yet.**

When RECLAIM started, these were all unknowns:
- Whether the Cytron MD10C would be powerful enough or need replacing
- Whether Teensy 4.1 had enough pins and processing for both motors AND arm
- What voltage the servo rail needed (ended up being 6V, not 5V)
- How many Wago connectors would actually be needed
- Whether the LiDAR and camera would even work together on the same USB bus

Every one of those required a physical change — swapping a component, rewiring a rail, adding a connector. On a custom PCB, each of those changes is a new board spin ($150-500 and 2-3 weeks lead time). On a breadboard/module setup, it's 20 minutes with a screwdriver.

**Prototype philosophy:**
- Modules are expensive per-unit but cheap to replace and reconfigure
- Wiring is messy but infinitely flexible
- Fuse block is bulky but fuse ratings can change same day
- Teensy is $35 but if fried, plug in another one

**Things that actually changed mid-prototype:**
1. Motor driver choice (learned 3.3V logic compatibility requirement)
2. Power distribution (added 6V buck mid-project for servos)
3. Serial protocol tuning (discovered Teensy serial contention with odom + drive)
4. Encoder wiring (learned 3.3V vs 5V tolerance issue)
5. Arm servo selection (changed gripper to LewanSoul claw mid-project)

None of that is predictable upfront. A PCB at prototype stage would have meant 4-5 board respins.

## Why PCB is Right for the Product

**1. Size and weight** — Current power distribution takes ~30×20×10cm. Equivalent PCB: 15×10×2cm.

**2. Reliability** — Every Wago connector, JST crimp, and spade terminal is a potential failure point. PCB traces don't come loose. Soldered connections don't vibrate apart.

**3. Repeatability** — To build a second prototype robot today requires rewiring everything by hand. With a PCB, order 10 boards, populate them, done.

**4. Integration** — STM32 talks to DRV8243 via controlled-impedance SPI trace 2cm away. Lower noise, faster communication, no flying leads picking up motor EMI.

**5. Safety features** — Hardware overcurrent protection, reverse polarity protection, and E-stop logic can't easily be added to a module system. On a PCB these are designed in from day one.

**6. Cost at scale** — Cytron MD10C: $20×2 = $40. DRV8243 on PCB: $3×2 = $6. Every component is 5-10× cheaper without the module markup.

---

## Finalized Component List

| Subsystem | Component | Confirmed |
|---|---|---|
| Compute | Jetson Orin NX (reComputer J4012) | ✅ |
| MCU | STM32F405RGT6 | ✅ |
| Drive motors | Pololu 37D 12V 100:1 w/ 64CPR encoders | ✅ |
| Motor drivers | 2× DRV8243 (on PCB) | ✅ |
| Arm | CubeMars AK70-10, AK80-9, AK60-6, 2×AK10-9 | ✅ |
| Gripper | ROBOTIS XM430 | ✅ |
| Camera | OAK-D Pro (eye-in-hand) | ✅ |
| LiDAR | Livox Mid-360 3D LiDAR | ✅ |
| Battery | 25.6V 20Ah LiFePO4 | ✅ |
| Status light | WS2812B 16-LED ring | ✅ |
| Work light | Cree XHP35 + PT4115 driver | ✅ |
| IMU | ICM-42688-P (on PCB) | ✅ |
| CAN transceiver | SN65HVD230 (on PCB) | ✅ |
| E-stop | Latching mushroom + power relay | ✅ |
| Power monitoring | INA226 per rail | ✅ |
| Cliff detection | Under review — see notes | 🔄 |
| Bumper switches | 4× microswitch | ✅ |

---

## Component Justification

### MCU — STM32F405RGT6

**Why not keep Teensy 4.1?**
The Teensy is a hobbyist dev board. Problems for product:
- Dev board mounted on carrier — wasteful, second failure surface
- No hardware CAN bus — would need external MCP2515 SPI CAN controller
- USB connector only interface — fragile in vibration/EMI environments

**Why STM32F405 over other STM32s:**
- Cortex-M4 at 168MHz with FPU — handles 1kHz control loops comfortably
- Hardware CAN1 + CAN2 — two independent CAN buses for CubeMars + spare
- 3× hardware encoder timers (TIM1, TIM2, TIM3) — zero CPU overhead tick counting
- micro-ROS production-tested on STM32F4 — reference platform for micro-ROS team
- Same chip as Pixhawk v1/v2 — most battle-tested robotics controller ever built
- $5 in quantity vs $35 Teensy

**Why not STM32H743?** Overkill — F405 handles 100Hz loops with headroom. H743 adds complexity for no practical benefit here.

**Why not RP2040?** No hardware CAN. PIO is clever but a workaround for missing hardware.

### IMU — ICM-42688-P

**Why add an IMU at all?**
Prototype relies entirely on wheel encoders for odometry. Known failure modes:
- Wheel slip when starting/stopping
- Castor drag causing yaw drift (observed — why heading hold exists)
- Accumulated encoder error over long distances

IMU adds gyroscope yaw rate for sensor fusion — gyro sees instantaneous angular velocity with no slip, no tick accumulation. Critical for accurate 360° scans.

**Why ICM-42688-P specifically:**

| IMU | Gyro noise | ODR | Interface |
|-----|---|-----|---|
| MPU-6050 | 0.005°/s/√Hz | 1kHz | I2C only |
| LSM6DSO | 0.004°/s/√Hz | 6.6kHz | SPI/I2C |
| **ICM-42688-P** | **0.0028°/s/√Hz** | **32kHz** | **SPI** |

Lowest noise floor of any consumer MEMS IMU. Used in DJI flight controllers. Gyro noise directly translates to target position error during scans.

### Motor Drivers — DRV8243

**Why not keep Cytron MD10C?**
MD10C is a module with its own PCB, connectors, mounting — wasteful for product. More importantly:

| Feature | Cytron MD10C | DRV8243 on PCB |
|---|---|---|
| Current sensing | None | Built-in (±5%) |
| Fault reporting | LED only | SPI register + fault pin |
| Thermal shutdown | Unknown | Yes, programmable |
| Overcurrent protection | External fuse only | Cycle-by-cycle limiting |
| Closed-loop torque | No (no current feedback) | Yes |
| Size | 55×37mm external | 5×6mm on PCB |
| Cost | $20 each | $3 each |

Current sensing enables: stall detection, torque-limited driving, surface estimation (carpet vs tile shows different motor current signatures).

**Why not DRV8874?** Only 6A continuous — borderline for Pololu 37D stall (~5A). DRV8243 is 8A continuous, 12A peak — proper headroom.

### Two Lights — Status vs Work

**Different purposes entirely:**

**Status light (WS2812B ring):**
- Tells the story of what robot is doing without reading a terminal
- Operators know at a glance if robot is working, stuck, or errored
- Safety signaling: solid red = hardware fault, don't approach
- One GPIO pin, no external driver
- Color scheme: Blue=SCAN, Yellow=APPROACH, Green=ALIGNED, Red=ERROR

**Work light (Cree XHP35 + PT4115):**
- OAK-D Pro needs adequate illumination for reliable YOLO detection
- Post-event venues can be dim (loading docks, large dark halls)
- 350 lumens aimed at floor 30° ahead — detection confidence improves significantly on dark objects
- PT4115 constant-current driver — brightness set by one resistor, MCU can PWM-dim for power saving
- Tested in prototype: detection confidence dropped ~15% in dim conditions

### CAN Bus — Why It's Right for CubeMars

**Protocol comparison:**

| Protocol | Update rate | Feedback | Wiring | Used by CubeMars |
|---|---|---|---|---|
| PWM (prototype) | 50Hz | None | 1 wire/joint | No |
| RS-485/Dynamixel | 57.6k-4Mbps | Yes | Daisy chain | No |
| EtherCAT | 100Mbps | Yes | Complex | No |
| **CAN bus** | **1Mbps** | **Yes** | **Daisy chain** | **Yes — native** |

CAN bus advantages:
- All 6 actuators on one twisted pair — daisy chained joint to joint
- Bidirectional: each actuator sends position, velocity, torque, temperature every cycle
- Error detection: CRC + acknowledgment + error counters built into protocol
- Electrically robust: differential signaling, immune to motor EMI
- At 1kHz per joint: 6 × 64bit × 1000 = 384kbps — well under 1Mbps limit

**CAN transceiver (SN65HVD230):** $0.80 IC that converts STM32's 3.3V CAN_TX/CAN_RX to differential CAN_H/CAN_L. Mandatory — handles bus termination, common-mode rejection, STM32 protection.

### Safety — Cliff Detection Discussion

**The case for cliff sensors (VL53L1X pointing down at robot edges):**
- Post-event venues can have stage drops, loading dock platforms, ramp edges
- Even with Nav2 + a map, if the robot drifts or the map is slightly wrong it could approach an edge
- Cliff sensors are a hardware failsafe independent of software

**The case against (for our specific use case):**
- Venues will be mapped before deployment — Nav2 will have known boundaries
- The Livox Mid-360 3D LiDAR already detects drops as geometry changes
- The robot operates at low speed (0.57 m/s) — stopping distance is short
- Adding 4× VL53L1X + routing adds PCB complexity for a low-probability scenario

**Can the OAK-D Pro handle this?**
Partially — the depth camera detects geometry changes ahead of the robot. But limitations:
- Eye-in-hand mount: camera moves with arm, FOV changes during picks
- Blind spot directly below and beside the robot
- Depth accuracy degrades at edges with low texture
- Already saturated processing YOLO at 30fps

**Decision:** Livox Mid-360 + Nav2 boundary enforcement is the primary cliff protection.
Add bumper switches as contact-level fallback. VL53L1X cliff sensors are optional —
add PCB footprints but don't populate initially. Validate in venue testing.

---

## Safety Architecture Summary

**Layer 1 — Mapping (Nav2):** Robot knows venue boundaries, won't plan paths near edges

**Layer 2 — LiDAR safety zones:**
- 0-0.5m: E-stop
- 0.5-1.5m: Slow to 0.1 m/s
- ISO 3691-4 compliant mobile robot behavior

**Layer 3 — Contact (bumper switches):** 4× microswitch bumpers → hardware interrupt to MCU → instant E-stop

**Layer 4 — Hardware E-stop:** Latching mushroom button → MOSFET cuts motor driver EN pins → independent of software

**Layer 5 — Status lighting:** Solid red + buzzer when any safety layer triggers

---

## Power Architecture

**Battery:** 25.6V 20Ah LiFePO4 (~512Wh, ~4 hours typical)

**Why 25.6V (2S) instead of 12.8V:**
- Halves current draw at same power → thinner wires, less heat
- CubeMars actuators optimal at 24V
- Drive motors run at 24V → faster, more torque than 12V equivalent
- Jetson needs 12V buck anyway (already needed)

**Rails:**
| Rail | Voltage | Load | Source |
|---|---|---|---|
| Main | 25.6V | CubeMars arm | Direct battery |
| Motor | 25.6V | Drive motors via DRV8243 | Direct battery |
| Compute | 12V | Jetson Orin NX | Buck converter |
| Logic | 5V | USB peripherals | Buck from 12V |
| MCU | 3.3V | STM32, IMU, transceivers | LDO from 5V |

**Power monitoring:** INA226 on each rail — I2C, 0.1% accuracy, reports voltage + current to STM32 → published to ROS2 → battery state estimation + alerts.

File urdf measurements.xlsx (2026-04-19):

 | X (forward +) | Y (left +) | Z (up +)
J1: J2 | 15 | -12 | 15
J2: J3 | 0 | 0 | 104
J3:J4 | 0 | 0 | 148.5
J4:J5 | 69.69 | 36.2 | 0
J5:J6 | 23 | 12 | -27.5
J6: Claw tip meeting point | 90 | -12 | 27.5

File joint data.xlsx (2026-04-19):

 |  | Dx (forward) | Dy (left) | Dz (up) | Axis (rpy)
J1 | J2 | -1.8 | -3.5 | 1 | (0,0,1)
J2 | J3 | 0 | 0 | 10.4 | (0,1,0)
J3 | J4 | 0 | 0 | 14.5 | (0,1,0)
J4 | J5 | 0 | 3.7 | 7.2 | (0,1,0)
J5 | J6 | 0 | 1.5 | 2.7 | (0,0,1)
J6 | Tool | 0 | -1.4 | 9 | (1,0,0)
 | Min | Max | Min | Max
J1 | -148 | 148 | 400us | 2600us | J1 | 400us | 2600
J2 | -135 | 135 | 960us | 2400us | J2 | 650 | 2200
J3 | -148 | 110 | 400us | 2600us
J4 | -99 | 99 | 400us | 2600us
J5 | -99 | 99 | 400us | 2600us
J6 | 7 | 70 | 400us | 2600us
POSES:
home = 38.0 83.0 65.0 -85.0 18.0 7.0
bin1_pre = 125.0 43.0 75.0 -44.0 18.0 70.0
bin1_drop = 125.0 23.0 75.0 -44.0 18.0 7.0
bin2_pre = -45.0 43.0 75.0 -44.0 18.0 70.0
bin2_drop = -45.0 23.0 75.0 -44.0 18.0 7.0
bin3_pre = -125.0 43.0 75.0 -44.0 18.0 70.0
bin3_drop = -125.0 23.0 75.0 -44.0 18.0 7.0
prepicking = 38.0 13.0 65.0 -85.0 18.0 7.0
picking = 38.0 -32.0 65.0 -15.0 18.0 7.0
almostpicking = 38.0 -52.0 65.0 -45.0 18.0 7.0
pickedup = 38.0 -52.0 65.0 -45.0 18.0 57.0
J1 | 1210us | -35.6
J2 | 1870us | 78 |  |  | Max 700,2000

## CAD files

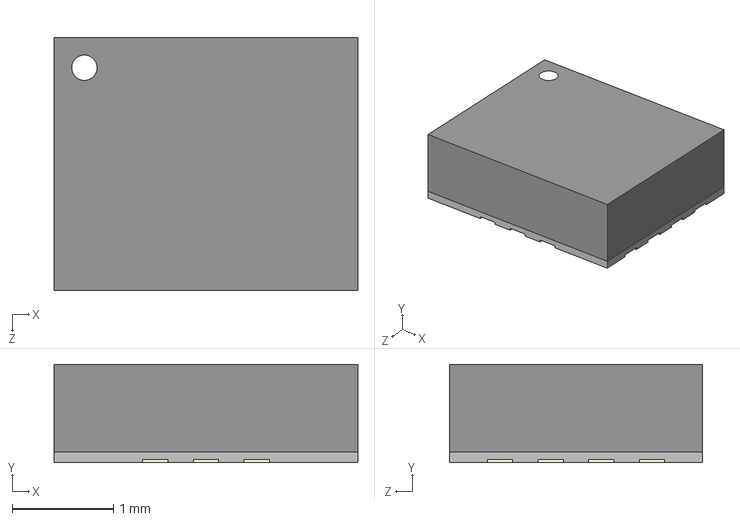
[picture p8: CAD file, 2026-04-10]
docs/product_pcb_electrical/kicad_project/custom_libs/ICM-42688-P/ICM-42688-P.step
3.00 x 0.97 x 2.50 mm

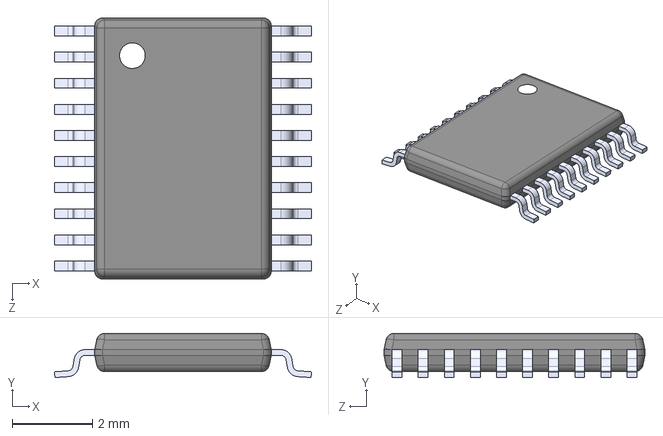
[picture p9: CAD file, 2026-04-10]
docs/product_pcb_electrical/kicad_project/custom_libs/LM5116MHX_NOPB/LM5116MHX_NOPB.step
6.40 x 1.10 x 6.50 mm

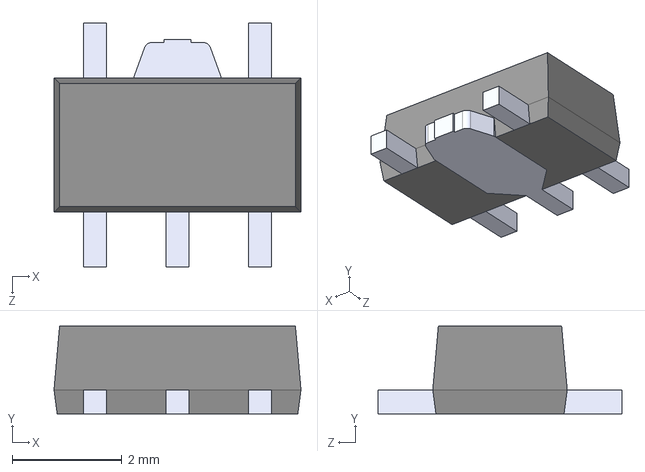
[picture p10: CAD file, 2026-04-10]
docs/product_pcb_electrical/kicad_project/custom_libs/PT4115/PT4115.step
4.50 x 1.60 x 4.45 mm

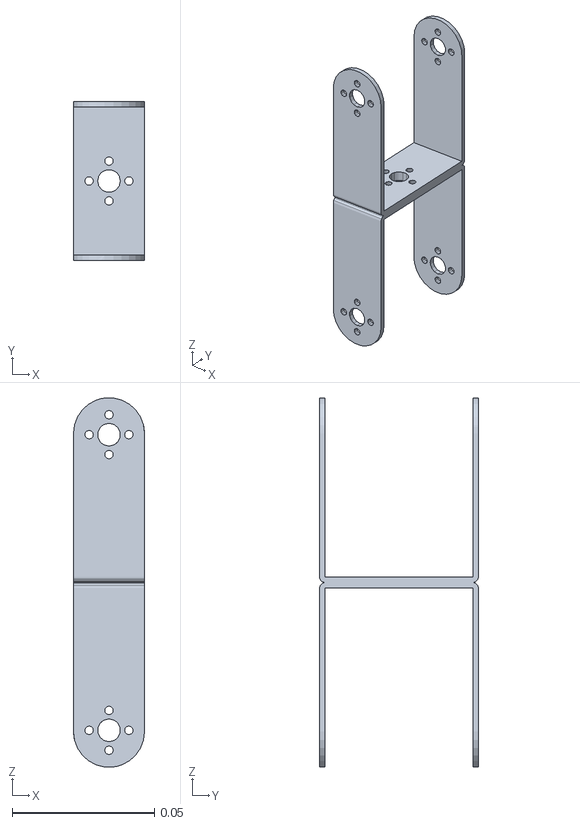
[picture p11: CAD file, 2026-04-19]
foxglove_arm/meshes/upper_arm_link.STL
0.025 x 0.056 x 0.13

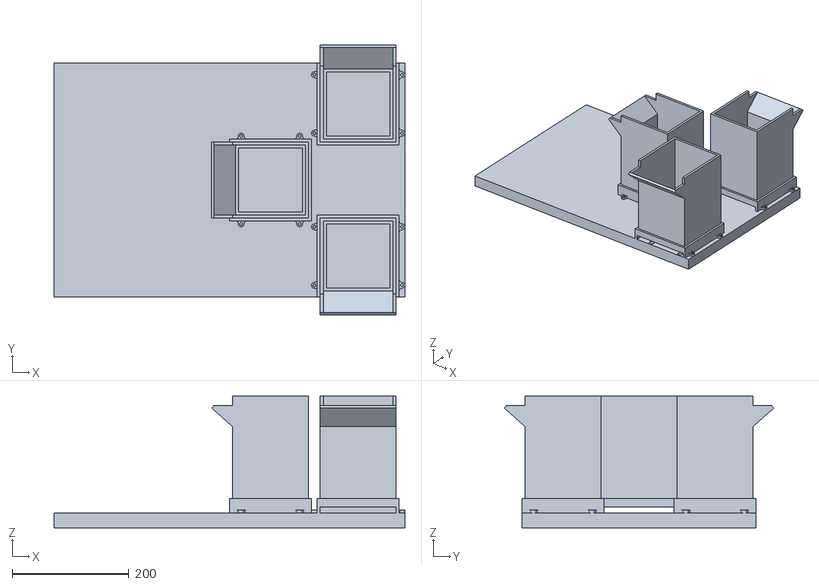
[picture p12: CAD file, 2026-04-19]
reclaim_ws/src/reclaim_arm_moveit_config/meshes/environment.stl
600.0 x 460.9 x 225.4

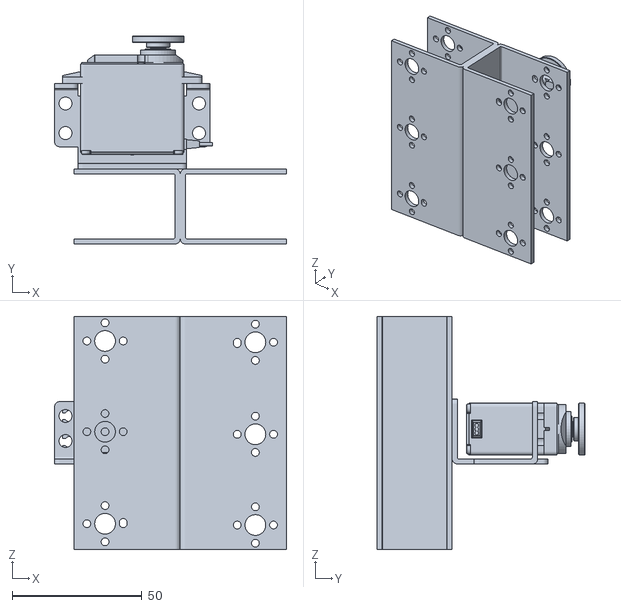
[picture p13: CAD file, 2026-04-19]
reclaim_ws/src/reclaim_control/meshes/base_rotation.stl
89.5 x 80.2 x 90.0

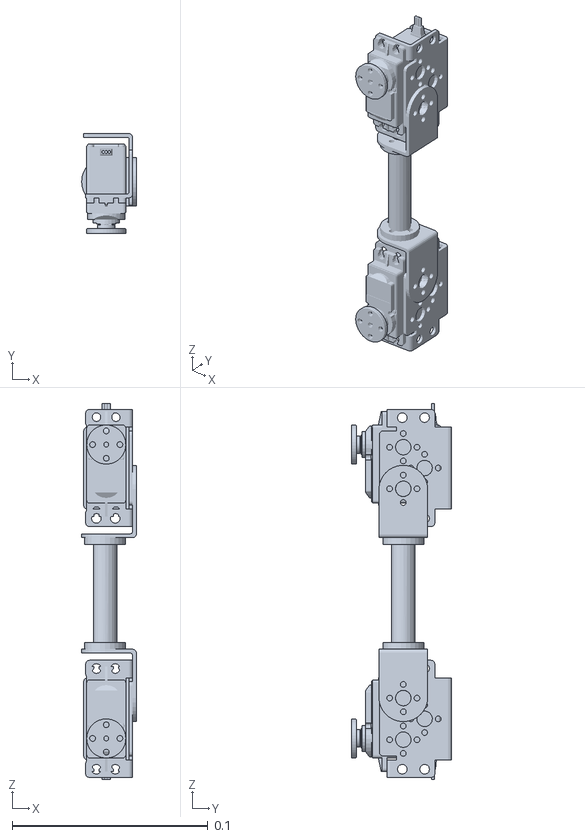
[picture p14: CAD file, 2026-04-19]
URDF Arm Model/meshes/forearm_link.STL
0.028 x 0.0513 x 0.192

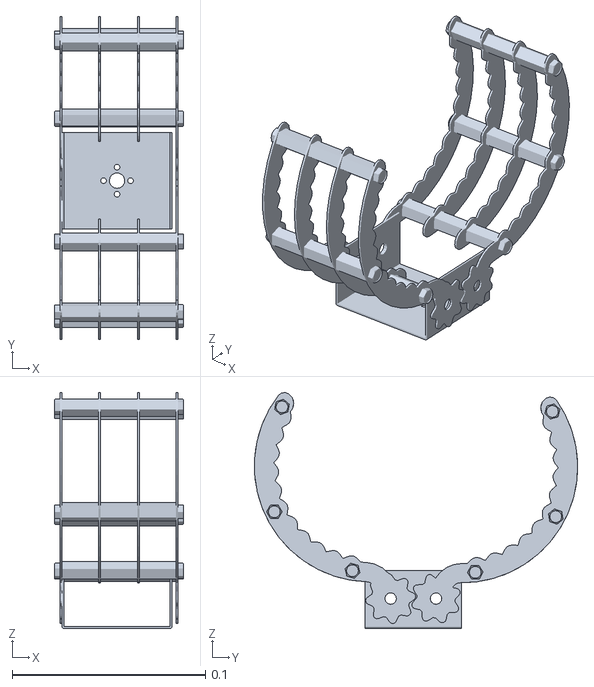
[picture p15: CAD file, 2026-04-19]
foxglove_arm/meshes/tool0.STL
0.067 x 0.168 x 0.122

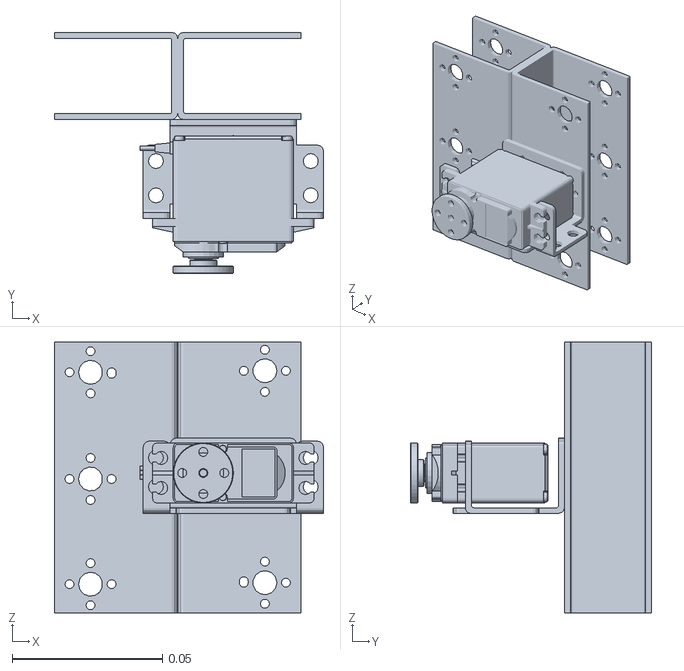
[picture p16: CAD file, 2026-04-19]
URDF Arm Model/meshes/base_link.STL
0.0895 x 0.0803 x 0.09

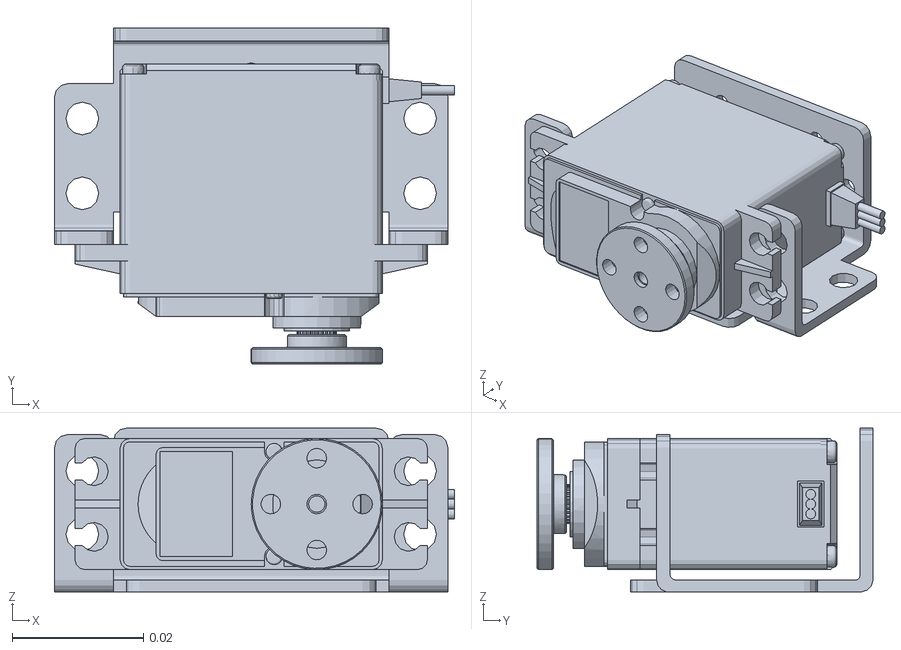
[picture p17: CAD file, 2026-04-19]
foxglove_arm/meshes/shoulder_link.STL
0.061 x 0.0513 x 0.025

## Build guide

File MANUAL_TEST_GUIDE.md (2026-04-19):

# RECLAIM Manual Testing Guide

**All commands run from your Mac terminal.** No interactive SSH needed.

**Prerequisites:**
- Connected to MIC-711's WiFi (Mango router)
- `ssh mic` alias configured in `~/.ssh/config`
- Battery connected and charged

---

## QUICK REFERENCE

| Action | Command |
|---|---|
| **Stop everything** | `ssh mic "pkill -9 -f waste_tracker; pkill -9 -f teensy_bridge; for p in /dev/ttyACM*; do echo 'ESTOP' > \$p 2>/dev/null; done"` |
| **Emergency stop** | `ssh mic "for p in /dev/ttyACM*; do echo 'ESTOP' > \$p 2>/dev/null; done"` |
| **Rescan** | `ssh mic "source ~/miniforge3/etc/profile.d/conda.sh && conda activate ros_env && ros2 topic pub /rescan std_msgs/msg/String '{data: go}' -1"` |
| **Watch logs** | `ssh mic "tail -f /tmp/tracker.log"` |
| **Check status** | `ssh mic "tail -20 /tmp/tracker.log"` |
| **Check bridge** | `ssh mic "tail -5 /tmp/bridge.log"` |
| **View camera** | `http://192.168.2.2:8081` in browser (TRT server must be running) |
| **Diag monitor** | `python3 diag_monitor.py` (run on Mac, receives UDP from TRT V2) |

---

## FULL SYSTEM — Drive + Arm + Pick & Place (showcase demo)

**Requires 7 terminals on MIC-711.** Use NoMachine to access the MIC-711 desktop for RViz.
Open each terminal in order — wait for the indicated message before proceeding.

### Terminal 1 — Teensy Bridge
```bash
echo 'mic-711' | sudo -S chmod 666 /dev/ttyACM0 && \
source ~/miniforge3/etc/profile.d/conda.sh && conda activate ros_env && \
cd ~/reclaim_ws && source install/setup.bash && \
ros2 run reclaim_control teensy_bridge
```
**Wait for:** `TeensyBridge started`

### Terminal 2 — MoveGroup + RViz (on MIC-711 desktop via NoMachine)
```bash
export DISPLAY=:0 && source ~/miniforge3/etc/profile.d/conda.sh && conda activate ros_env && \
cd ~/reclaim_ws && source install/setup.bash && \
ros2 launch reclaim_arm_moveit_config move_group.launch.py
```
**Wait for:** `You can start planning now!`

### Terminal 3 — Planning Scene (collision objects)
```bash
source ~/miniforge3/etc/profile.d/conda.sh && conda activate ros_env && \
cd ~/reclaim_ws && source install/setup.bash && \
python3 src/reclaim_arm_moveit_config/scripts/load_planning_scene.py
```

### Terminal 4 — TRT Camera Server
```bash
kill $(lsof -t -i:8081) 2>/dev/null; \
env -i HOME=/home/mic-711 PATH=/usr/bin:/usr/local/bin:/bin \
python3.8 ~/reclaim_ws/tests/camera_detect_trt.py \
  --model ~/reclaim_ws/models/waste_yolo11n_v3_best.engine \
  --conf 0.35 --port 8081
```
**Wait for:** `Running...`

### Terminal 5 — Move Arm to Search Pose (in RViz GUI)
In the RViz window (via NoMachine):
1. In the MotionPlanning panel → "Planning" tab
2. Set **Goal State** dropdown → `search`
3. Click **Plan & Execute**
4. Wait for arm to finish moving

### Terminal 6 — Pick & Place Listener
```bash
source ~/miniforge3/etc/profile.d/conda.sh && conda activate ros_env && \
cd ~/reclaim_ws && source install/setup.bash && \
python3 src/reclaim_arm_moveit_config/scripts/pick_and_place.py --listen --port 8081
```

### Terminal 7 — Waste Tracker (starts scanning immediately)
```bash
source ~/miniforge3/etc/profile.d/conda.sh && conda activate ros_env && \
cd ~/reclaim_ws && source install/setup.bash && \
ros2 run reclaim_bringup waste_tracker_trt --ros-args \
  -p trt_url:=http://localhost:8081 \
  -p drive_only:=false
```

### Mac — View Camera Stream
```bash
# Set up SSH tunnel (run once)
lsof -ti:8081 | xargs kill -9 2>/dev/null; ssh -f -N -L 8081:127.0.0.1:8081 mic
# Then open in browser:
open http://127.0.0.1:8081
```

### Mac — View Arm in Foxglove (optional)
Open Foxglove app → Connect to `ws://192.168.2.2:8765` → Add 3D panel → Load URDF

### Mac — NoMachine (see RViz on MIC-711 desktop)
Open NoMachine → Connect to 192.168.2.2 → You see the MIC-711 desktop with RViz

### Shutdown Full System
```bash
# On MIC-711 (any terminal):
pkill -9 -f waste_tracker
pkill -9 -f pick_and_place
pkill -9 -f camera_detect_trt
pkill -9 -f move_group
pkill -9 -f teensy_bridge
echo 'ESTOP' > /dev/ttyACM0 2>/dev/null
```

---

## START — TRT V2 (30fps, recommended)

**Requires TRT server already running** (friend starts it, or see "Start TRT Server" below).

### Step 1: Start bridge
```bash
ssh mic "pkill -9 -f teensy_bridge" 2>/dev/null; sleep 2; \
echo 'mic-711' | ssh mic "sudo -S chmod 666 /dev/ttyACM*" 2>/dev/null; \
ssh mic "source ~/miniforge3/etc/profile.d/conda.sh && conda activate ros_env && cd ~/reclaim_ws && source install/setup.bash && TEENSY_PORT=\$(ls /dev/ttyACM* 2>/dev/null | head -1) && echo \"Using \$TEENSY_PORT\" && nohup ros2 run reclaim_control teensy_bridge --ros-args --params-file src/reclaim_control/config/teensy_bridge.yaml -p serial_port:=\$TEENSY_PORT > /tmp/bridge.log 2>&1 &"; \
sleep 2; ssh mic "tail -3 /tmp/bridge.log"
```

### Step 2: Start TRT V2 tracker
```bash
ssh mic "pkill -9 -f waste_tracker" 2>/dev/null; sleep 2; \
ssh mic "source ~/miniforge3/etc/profile.d/conda.sh && conda activate ros_env && cd ~/reclaim_ws && source install/setup.bash && nohup ros2 run reclaim_bringup waste_tracker_trt_v2 --ros-args -p drive_only:=true > /tmp/tracker.log 2>&1 &"; \
echo "Starting TRT V2..."; sleep 3; ssh mic "tail -5 /tmp/tracker.log"
```

### Step 3: Monitor on Mac (separate terminal tab)
```bash
python3 diag_monitor.py
```

### One-liner start (bridge + TRT V2)
```bash
ssh mic "pkill -9 -f waste_tracker; pkill -9 -f teensy_bridge" 2>/dev/null; sleep 3; \
echo 'mic-711' | ssh mic "sudo -S chmod 666 /dev/ttyACM*" 2>/dev/null; \
ssh mic "source ~/miniforge3/etc/profile.d/conda.sh && conda activate ros_env && cd ~/reclaim_ws && source install/setup.bash && TEENSY_PORT=\$(ls /dev/ttyACM* 2>/dev/null | head -1) && nohup ros2 run reclaim_control teensy_bridge --ros-args --params-file src/reclaim_control/config/teensy_bridge.yaml -p serial_port:=\$TEENSY_PORT > /tmp/bridge.log 2>&1 &"; \
sleep 2; \
ssh mic "source ~/miniforge3/etc/profile.d/conda.sh && conda activate ros_env && cd ~/reclaim_ws && source install/setup.bash && nohup ros2 run reclaim_bringup waste_tracker_trt_v2 --ros-args -p drive_only:=true > /tmp/tracker.log 2>&1 &"; \
echo "Starting..."; sleep 3; ssh mic "tail -5 /tmp/tracker.log"
```

---

## START — V1 (own camera, original)

```bash
ssh mic "pkill -9 -f waste_tracker; pkill -9 -f teensy_bridge; pkill -9 -f python3" 2>/dev/null; \
sleep 3; \
echo 'mic-711' | ssh mic "sudo -S chmod 666 /dev/ttyACM*" 2>/dev/null; \
ssh mic "source ~/miniforge3/etc/profile.d/conda.sh && conda activate ros_env && cd ~/reclaim_ws && source install/setup.bash && TEENSY_PORT=\$(ls /dev/ttyACM* 2>/dev/null | head -1) && echo \"Using \$TEENSY_PORT\" && nohup ros2 run reclaim_control teensy_bridge --ros-args --params-file src/reclaim_control/config/teensy_bridge.yaml -p serial_port:=\$TEENSY_PORT > /tmp/bridge.log 2>&1 &"; \
sleep 2; \
ssh mic "rm -f /tmp/tracker.log && source ~/miniforge3/etc/profile.d/conda.sh && conda activate ros_env && export LD_PRELOAD='/home/mic-711/miniforge3/envs/ros_env/lib/libstdc++.so.6:/home/mic-711/miniforge3/envs/ros_env/lib/python3.11/site-packages/torch/lib/libc10.so:/home/mic-711/miniforge3/envs/ros_env/lib/libgomp.so.1' && cd ~/reclaim_ws && source install/setup.bash && nohup ros2 run reclaim_bringup waste_tracker --ros-args --params-file src/reclaim_bringup/config/waste_tracker.yaml > /tmp/tracker.log 2>&1 &"; \
echo "Waiting 8s for camera..."; sleep 8; \
ssh mic "tail -5 /tmp/tracker.log"
```

---

## START — TRT V1 (30fps, conservative tuning)

```bash
ssh mic "pkill -9 -f waste_tracker" 2>/dev/null; sleep 2; \
ssh mic "source ~/miniforge3/etc/profile.d/conda.sh && conda activate ros_env && cd ~/reclaim_ws && source install/setup.bash && nohup ros2 run reclaim_bringup waste_tracker_trt --ros-args -p drive_only:=true > /tmp/tracker.log 2>&1 &"; \
echo "Starting TRT V1..."; sleep 3; ssh mic "tail -5 /tmp/tracker.log"
```

---

## SWITCH TRACKERS (bridge stays running)

```bash
# Kill current tracker
ssh mic "pkill -9 -f waste_tracker" 2>/dev/null; sleep 2

# Then start whichever one you want:

# TRT V2 (recommended):
ssh mic "source ~/miniforge3/etc/profile.d/conda.sh && conda activate ros_env && cd ~/reclaim_ws && source install/setup.bash && nohup ros2 run reclaim_bringup waste_tracker_trt_v2 --ros-args -p drive_only:=true > /tmp/tracker.log 2>&1 &"

# TRT V1:
ssh mic "source ~/miniforge3/etc/profile.d/conda.sh && conda activate ros_env && cd ~/reclaim_ws && source install/setup.bash && nohup ros2 run reclaim_bringup waste_tracker_trt --ros-args -p drive_only:=true > /tmp/tracker.log 2>&1 &"

# Original V1 (own camera — kills TRT server camera access):
ssh mic "source ~/miniforge3/etc/profile.d/conda.sh && conda activate ros_env && export LD_PRELOAD='/home/mic-711/miniforge3/envs/ros_env/lib/libstdc++.so.6:/home/mic-711/miniforge3/envs/ros_env/lib/python3.11/site-packages/torch/lib/libc10.so:/home/mic-711/miniforge3/envs/ros_env/lib/libgomp.so.1' && cd ~/reclaim_ws && source install/setup.bash && nohup ros2 run reclaim_bringup waste_tracker --ros-args --params-file src/reclaim_bringup/config/waste_tracker.yaml > /tmp/tracker.log 2>&1 &"
```

---

## STOP

### Stop tracker only (bridge keeps running)
```bash
ssh mic "pkill -9 -f waste_tracker"
```

### Stop everything
```bash
ssh mic "pkill -9 -f waste_tracker; pkill -9 -f teensy_bridge; for p in /dev/ttyACM*; do echo 'ESTOP' > \$p 2>/dev/null; done"; echo "Stopped."
```

### Emergency stop (instant motor kill, no process kill)
```bash
ssh mic "for p in /dev/ttyACM*; do echo 'ESTOP' > \$p 2>/dev/null; done"
```

---

## START TRT SERVER (if friend isn't running it)

```bash
ssh mic "nohup env -i HOME=/home/mic-711 PATH=/usr/local/bin:/usr/bin:/bin /usr/bin/python3.8 ~/reclaim_ws/tests/camera_detect_trt.py --model models/waste_yolo11n_v3_best.engine --conf 0.15 --port 8081 > /tmp/trt_server.log 2>&1 &"; \
sleep 5; ssh mic "tail -5 /tmp/trt_server.log"
```

### Stop TRT server
```bash
ssh mic "pkill -9 -f camera_detect_trt"
```

### Check TRT server
```bash
ssh mic "curl -s http://localhost:8081/detection" | python3 -m json.tool
```

---

## VIEW CAMERA

### Browser (Mac)
Open `http://192.168.2.2:8081` — live MJPEG from TRT server with bounding boxes.

If that doesn't work, use SSH tunnel:
```bash
ssh -f -N -L 8081:localhost:8081 mic
# Then open http://localhost:8081
```

### Foxglove (for V1 only — V1 publishes debug image to ROS2)
```bash
ssh mic "source ~/miniforge3/etc/profile.d/conda.sh && conda activate ros_env && nohup ros2 launch foxglove_bridge foxglove_bridge_launch.xml > /tmp/foxglove.log 2>&1 &"
# Open Foxglove Studio → ws://192.168.2.2:8765 → Image panel → /perception/debug_image
```

---

## MONITORING

### Live tracker log
```bash
ssh mic "tail -f /tmp/tracker.log"
```

### Live diagnostics dashboard (TRT V2 only)
```bash
python3 diag_monitor.py
```
Shows: state, target, depth, pixel offset bar, motor commands, detection rate, lost count.
Auto-saves to `diag_log_*.jsonl` on your Mac.

### Check tuning log (TRT V2 only — on MIC-711)
```bash
# View current tuning parameters
ssh mic "cat /tmp/tracker_tuning_params.txt"

# Download tuning CSV to Mac for analysis
scp mic:/tmp/tracker_tuning.csv ~/Documents/RECLAIM/
```

### Run summary (TRT V2 — printed automatically when run completes)
Look for `RUN SUMMARY` in the tracker log after it reaches ALIGN/IDLE.

---

## RESCAN (restart state machine without restarting processes)

```bash
ssh mic "source ~/miniforge3/etc/profile.d/conda.sh && conda activate ros_env && ros2 topic pub /rescan std_msgs/msg/String '{data: go}' -1"
```

---

## EDIT → SYNC → REBUILD → RESTART

### Sync TRT V2 only
```bash
# 1. Stop tracker
ssh mic "pkill -9 -f waste_tracker" 2>/dev/null; sleep 2

# 2. Sync file
rsync -avz ~/Documents/RECLAIM/reclaim_ws/src/reclaim_bringup/reclaim_bringup/waste_tracker_trt_v2.py \
  mic:~/reclaim_ws/src/reclaim_bringup/reclaim_bringup/

# 3. Build
ssh mic "source ~/miniforge3/etc/profile.d/conda.sh && conda activate ros_env && cd ~/reclaim_ws && colcon build --packages-select reclaim_bringup --symlink-install"

# 4. Restart
ssh mic "source ~/miniforge3/etc/profile.d/conda.sh && conda activate ros_env && cd ~/reclaim_ws && source install/setup.bash && nohup ros2 run reclaim_bringup waste_tracker_trt_v2 --ros-args -p drive_only:=true > /tmp/tracker.log 2>&1 &"; \
sleep 3; ssh mic "tail -5 /tmp/tracker.log"
```

### Sync V1 only
```bash
ssh mic "pkill -9 -f waste_tracker" 2>/dev/null; sleep 2; \
rsync -avz ~/Documents/RECLAIM/reclaim_ws/src/reclaim_bringup/reclaim_bringup/waste_tracker.py \
  mic:~/reclaim_ws/src/reclaim_bringup/reclaim_bringup/; \
ssh mic "source ~/miniforge3/etc/profile.d/conda.sh && conda activate ros_env && cd ~/reclaim_ws && colcon build --packages-select reclaim_bringup"
```

### Sync camera server (DEPTH_MAX change)
```bash
rsync -avz ~/Documents/RECLAIM/reclaim_ws/tests/camera_detect_trt.py mic:~/reclaim_ws/tests/
```

### Full safe sync (excludes friend's files)
```bash
./sync.sh reclaim_bringup
```

---

## TELEOP & DIRECT MOTOR

### Keyboard teleop
```bash
ssh -t mic "source ~/miniforge3/etc/profile.d/conda.sh && conda activate ros_env && ros2 run teleop_twist_keyboard teleop_twist_keyboard"
```
Keys: `i`=forward, `,`=back, `j`=left, `l`=right, `k`=stop, `q`/`z`=speed up/down

### Direct motor commands (bypasses ROS)
```bash
ssh mic "echo 'SETVEL 0.10 0.10' > \$(ls /dev/ttyACM* | head -1)"   # forward
ssh mic "echo 'SETVEL -0.10 0.10' > \$(ls /dev/ttyACM* | head -1)"  # spin left
ssh mic "echo 'SETVEL 0.0 0.0' > \$(ls /dev/ttyACM* | head -1)"     # stop
ssh mic "echo 'TICKS' > \$(ls /dev/ttyACM* | head -1)"               # read encoders
ssh mic "for p in /dev/ttyACM*; do echo 'ESTOP' > \$p 2>/dev/null; done"  # E-STOP
```

---

## CALIBRATION TESTS

### Straight line (0.5m at 0.1 m/s, sinusoidal profile)
```bash
scp ~/Documents/RECLAIM/reclaim_ws/tests/cal_straight.py mic:/tmp/ 2>/dev/null; \
ssh mic "source ~/miniforge3/etc/profile.d/conda.sh && conda activate ros_env && cd ~/reclaim_ws && source install/setup.bash && python3 /tmp/cal_straight.py"
```

### 360° spin test
```bash
ssh mic "source ~/miniforge3/etc/profile.d/conda.sh && conda activate ros_env && ros2 topic pub /cmd_vel geometry_msgs/msg/Twist '{angular: {z: 0.25}}' -r 10 --times 260"
# Then stop:
ssh mic "source ~/miniforge3/etc/profile.d/conda.sh && conda activate ros_env && ros2 topic pub /cmd_vel geometry_msgs/msg/Twist '{angular: {z: 0.0}}' -1"
```

---

## PROCESS CHECK

```bash
# What's running?
ssh mic "pgrep -fa 'waste_tracker\|teensy_bridge\|camera_detect\|foxglove'"

# What's holding the serial port?
ssh mic "ls -la /dev/ttyACM* 2>/dev/null && lsof /dev/ttyACM* 2>/dev/null"

# What's holding the camera?
ssh mic "lsof /dev/video* 2>/dev/null"
```

---

## TUNING REFERENCE

### TRT V2 — Code parameters (waste_tracker_trt_v2.py)
| Parameter | Value | Effect |
|---|---|---|
| `pid_kp` | 0.0012 | Higher = faster centering, more jitter |
| `pid_ki` | 0.0 | Disabled (causes drift) |
| `pid_kd` | 0.0 | Disabled (amplifies noise) |
| `angular_alpha` | 0.45 | EMA smoothing — lower = smoother, more lag |
| `angular_ramp_rate` | 0.6 | Angular accel limit — lower = smoother starts |
| `angular_deadband` | 0.015 | Smooth taper zone — lower = more responsive |
| `bbox_alpha` | 0.5 | Bbox smoothing — lower = less flicker, more lag |
| `Kalman Q` | 2.0 | Process noise — higher = more responsive |
| `Kalman R` | 10.0 | Measurement noise — lower = trust data more |
| `target_lost_threshold` | 30 | Frames before rescan (1s at 30fps) |
| `det_hold_max` | 4 | Hold detection during gaps (133ms) |
| `confirm_threshold` | 3 | Frames to confirm target |
| `approach_max_v` | 0.12 | Max forward speed (m/s) |
| `scan_vel` | 0.3 | Scan rotation speed (rad/s) |

### V1 — Code parameters (waste_tracker.py)
| Parameter | Value | Effect |
|---|---|---|
| `pid_kp` | 0.0010 | Proportional gain |
| `pid_ki` | 0.00008 | Integral gain (steady-state fix) |
| `pid_kd` | 0.0006 | Derivative gain (damping) |
| `angular_alpha` | 0.25 | Heavier EMA (noisier 10fps data) |
| `angular_ramp_rate` | 0.3 | Lower ramp for 20Hz tick |

### TRT Server — CLI args
| Arg | Default | Effect |
|-----|---|---|
| `--conf` | 0.35 | YOLO threshold (try 0.15 for more detections) |
| `--burst` | 5 | Depth averaging frames |
| `--port` | 8081 | HTTP port |
| `--model` | waste_yolo11n_v3_best.engine | Model path |

---

## AVAILABLE TRACKERS

| Command | Description | Camera | FPS |
|---|---|---|-----|
| `waste_tracker` | V1 original | Own OAK-D | ~10 |
| `waste_tracker_v2` | Experimental stop-look-drive | Own OAK-D | ~10 |
| `waste_tracker_trt` | TRT V1 (conservative) | TRT server | 30 |
| `waste_tracker_trt_v2` | TRT V2 (optimized) | TRT server | 30 |

**Note:** V1/V2 (own camera) and TRT trackers are mutually exclusive for the camera.
If TRT server is running, use `waste_tracker_trt` or `waste_tracker_trt_v2`.
If running V1/V2, the TRT server must NOT be running (both can't access OAK-D).

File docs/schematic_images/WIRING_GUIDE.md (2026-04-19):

# RECLAIM — KiCad Schematic Wiring Guide (Phil's Lab Style)

> **Purpose:** Reference for wiring all labels in the KiCad schematics. Updated to use **Phil's Lab conventions:**
> - **Power symbols** (`+12V`, `+5V`, `+3.3V`, `GND`) placed at every component pin that needs power — press `P` to place
> - **Global labels** (rectangle with pointed edge) for all cross-sheet signals — press `Ctrl+L` to place
> - **Net labels** only for signals that stay on the same sheet — press `L` to place
> - Signal flow: **left → right**, power **top → bottom**
>
> **Label types in these schematics:**
> - `(global_label)` = connects across ALL sheets automatically (shown as pointed rectangles)
> - Power symbols = `+12V`, `GND`, `+3.3V`, `+5V` — built-in KiCad power symbols, global scope
> - GND labels have been **removed** — place `GND` power symbols (press `P`, search "GND") at the positions noted below

---

## Phil's Lab Style Quick Reference

### What changed in the schematic files

| Before | After | How to place in KiCad |
|---|---|---|
| `(label "SPI1_SCK" ...)` | `(global_label "SPI1_SCK" (shape output) ...)` | `Ctrl+L` → type name |
| `(label "GND" ...)` | **REMOVED** — place GND power symbol | `P` → search "GND" |
| `(label "VCC_3V3" ...)` | `(global_label "VCC_3V3" (shape passive) ...)` | Already converted |

### GND power symbols to place (where old GND labels were removed)

| Sheet | Position | Near component |
|---|---|---|
| Product Power Distribution | (245, 125) | Buck 1 area |
| Product Power Distribution | (390, 212) | LDO area |
| Product Power Distribution | (290, 148) | Buck 2 area |
| Product Power Distribution | (157, 215) | E-stop relay area |
| Product STM32 MCU | (135, 228) | Decoupling caps area |
| Prototype Power Distribution | (240, 108) | Buck converter area |
| Prototype Teensy Motor Control | (42, 100) | Motor driver L area |
| Prototype Teensy Motor Control | (42, 195) | Motor driver R area |
| Prototype Peripherals | (58, 118) | IPC area |

### Signal direction shapes on global labels

| Shape | Meaning | Examples |
|---|---|---|
| `output` | MCU drives this signal | SPI1_SCK, CAN1_TX, ESTOP_RELAY_CTRL |
| `input` | MCU receives this signal | SPI1_MISO, CAN1_RX, ENC_L_A, BUMPER_FL |
| `bidirectional` | Both directions | I2C1_SCL, I2C1_SDA, ETHERNET |
| `passive` | Power rail / no direction | VCC_25V, VBAT, MOTOR_PWR_L |

### Phil's Lab rules to follow while wiring

1. **Every VDD/VCC pin** → place `+3.3V` or `+5V` or `+12V` power symbol (press `P`)
2. **Every GND pin** → place `GND` power symbol pointing down (press `P`)
3. **Decoupling caps** → place RIGHT NEXT to the IC, between VDD pin and GND
4. **Short wires only** (2-4 grid squares) between components and their power symbols
5. **Components that share a function** → group together physically on the schematic
6. **No long power bus wires** — just place a new power symbol at each component

---

## Table of Contents

1. [Prototype — Power Distribution](#1-prototype--power-distribution)
2. [Prototype — Teensy & Motor Control](#2-prototype--teensy--motor-control)
3. [Prototype — Peripherals & Sensors](#3-prototype--peripherals--sensors)
4. [Product — Power Distribution & E-Stop](#4-product--power-distribution--e-stop)
5. [Product — STM32 MCU](#5-product--stm32-mcu)
6. [Product — Motor Drivers, CAN, IMU & Power Monitors](#6-product--motor-drivers-can-imu--power-monitors)
7. [Product — Connectors, LEDs, USB & Peripherals](#7-product--connectors-leds-usb--peripherals)
8. [Cross-Sheet Net Label Reference](#8-cross-sheet-net-label-reference)

---

## 1. Prototype — Power Distribution

**Sheet:** `Power_Distribution.kicad_sch`
**Page size:** A3

### Components

| Ref | Value | Description |
|-----|---|---|
| J_BAT | Battery 12.8V | ZapLitho LiFePO4 battery connector (2-pin) |
| SW_DC | DC Disconnect | DPST switch / XT60 kill switch |
| F1 | 5A | Fuse — MIC-711 compute channel |
| F2 | 10A | Fuse — Motor driver L channel |
| F3 | 10A | Fuse — Motor driver R channel |
| F4 | 20A | Fuse — Servo buck converter channel |
| U_BUCK | XINGYHENG 12V→6.8V | 20A 300W buck converter for servo bus |
| C_BULK | 10000uF 16V | Bulk electrolytic cap on servo bus |
| WAGO_V1 | 221-415 VCC | Wago lever-nut — servo VCC distribution (row 1) |
| WAGO_V2 | 221-415 VCC | Wago lever-nut — servo VCC distribution (row 2) |
| WAGO_G1 | 221-415 GND | Wago lever-nut — servo GND distribution (row 1) |
| WAGO_G2 | 221-415 GND | Wago lever-nut — servo GND distribution (row 2) |
| J1_PWR | J1 Base | Servo power connector — J1 base rotation (DS3218) |
| J2_PWR | J2 Shoulder | Servo power connector — J2 shoulder (DS3235) |
| J3_PWR | J3 Elbow | Servo power connector — J3 elbow (DS3218) |
| J4_PWR | J4 WristP | Servo power connector — J4 wrist pitch (DS3218) |
| J5_PWR | J5 WristR | Servo power connector — J5 wrist rotate (MG996R) |
| J6_PWR | J6 Gripper | Servo power connector — J6 gripper (DS3218 + LewanSoul) |
| #PWR001 | +12V | Power symbol |
| #PWR002 | GND | Power symbol |
| #PWR003 | PWR_FLAG | ERC power flag |
| #PWR004 | PWR_FLAG | ERC power flag |

### Wiring Instructions

| Wire From | Wire To | Net Name | Notes |
|---|---|---|---|
| J_BAT pin 1 | Label `VBAT` | VBAT | Battery positive terminal |
| J_BAT pin 2 | GND symbol | GND | Battery ground |
| Label `VBAT` | SW_DC pin 1 | VBAT | Battery voltage to switch |
| SW_DC pin 2 | Label `VBAT_SWITCHED` | VBAT_SWITCHED | Switched battery voltage |
| Label `VBAT_SWITCHED` | F1 pin 1 | — | Direct wire to fuse input |
| F1 pin 2 | Label `VBAT_FUSED_1` | VBAT_FUSED_1 | → MIC-711 (on Peripherals sheet) |
| Label `VBAT_SWITCHED` | F2 pin 1 | — | Direct wire |
| F2 pin 2 | Label `VBAT_FUSED_2` | VBAT_FUSED_2 | → Motor driver L (on Teensy sheet) |
| Label `VBAT_SWITCHED` | F3 pin 1 | — | Direct wire |
| F3 pin 2 | Label `VBAT_FUSED_3` | VBAT_FUSED_3 | → Motor driver R (on Peripherals sheet) |
| Label `VBAT_SWITCHED` | F4 pin 1 | — | Direct wire |
| F4 pin 2 | Label `VBAT_FUSED_4` | VBAT_FUSED_4 | → Servo buck (on Teensy sheet) |
| Label `VBAT_FUSED_4` | U_BUCK pin 1 | — | Buck converter VIN+ |
| U_BUCK pin 2 | Label `V_SERVO` | V_SERVO | Buck converter VOUT+ (6.8V) |
| U_BUCK pin 3 | GND symbol | GND | Buck converter VIN− |
| U_BUCK pin 4 | GND symbol | GND | Buck converter VOUT− |
| Label `V_SERVO` | C_BULK pin 1 | — | Bulk cap positive |
| GND symbol | C_BULK pin 2 | — | Bulk cap negative |
| Label `V_SERVO` | WAGO_V1 pin 1 | — | VCC Wago row 1 input |
| Label `V_SERVO` | WAGO_V2 pin 1 | — | VCC Wago row 2 input |
| GND symbol | WAGO_G1 pin 1 | — | GND Wago row 1 input |
| GND symbol | WAGO_G2 pin 1 | — | GND Wago row 2 input |
| WAGO_V1 pin 2 | J1_PWR pin 1 | — | J1 servo VCC |
| WAGO_G1 pin 2 | J1_PWR pin 2 | — | J1 servo GND |
| WAGO_V1 pin 3 | J2_PWR pin 1 | — | J2 servo VCC |
| WAGO_G1 pin 3 | J2_PWR pin 2 | — | J2 servo GND |
| WAGO_V1 pin 4 | J3_PWR pin 1 | — | J3 servo VCC |
| WAGO_G1 pin 4 | J3_PWR pin 2 | — | J3 servo GND |
| WAGO_V2 pin 2 | J4_PWR pin 1 | — | J4 servo VCC |
| WAGO_G2 pin 2 | J4_PWR pin 2 | — | J4 servo GND |
| WAGO_V2 pin 3 | J5_PWR pin 1 | — | J5 servo VCC |
| WAGO_G2 pin 3 | J5_PWR pin 2 | — | J5 servo GND |
| WAGO_V2 pin 4 | J6_PWR pin 1 | — | J6 servo VCC |
| WAGO_G2 pin 4 | J6_PWR pin 2 | — | J6 servo GND |
| +12V symbol | J_BAT pin 1 | +12V | Power flag for ERC |
| PWR_FLAG symbol | VBAT net | — | ERC flag |
| PWR_FLAG symbol | GND net | — | ERC flag |

---

## 2. Prototype — Teensy & Motor Control

**Sheet:** `Teensy_Motor_Control.kicad_sch`
**Page size:** A3

### Components

| Ref | Value | Description |
|-----|---|---|
| U_MCU | Teensy 4.1 | Main microcontroller (Conn_02x24, 48 pins total) |
| U_DRV_L | MD13C R3 | Motor driver left (MD10C, 6-pin connector) |
| U_DRV_R | BTS7960 | Motor driver right (8-pin connector) |
| M_L | JGB37-520 L | Left drive motor connector (6-pin: M1, M2, VCC, GND, OutA, OutB) |
| M_R | JGB37-520 R | Right drive motor connector (6-pin) |
| SIG_J1 | J1 Base P10 | Servo signal wire — Teensy pin 10 |
| SIG_J2 | J2 Shldr P11 | Servo signal wire — Teensy pin 11 |
| SIG_J3 | J3 Elbow P12 | Servo signal wire — Teensy pin 12 |
| SIG_J4 | J4 WrstP P13 | Servo signal wire — Teensy pin 13 |
| SIG_J5 | J5 WrstR P14 | Servo signal wire — Teensy pin 14 |
| SIG_J6 | J6 Grip P15 | Servo signal wire — Teensy pin 15 |
| #PWR101 | +12V | Power symbol |
| #PWR102 | GND | Power symbol |
| #PWR103 | +3V3 | Power symbol |

### Wiring Instructions — Left Motor Driver (U_DRV_L → MD10C)

| Wire From | Wire To | Net Name | Notes |
|---|---|---|---|
| Label `VBAT_FUSED_2` | U_DRV_L pin 1 (VIN) | VBAT_FUSED_2 | 12V from fuse block |
| Label `PWM_L` | U_DRV_L pin 2 (PWM) | PWM_L | → Teensy pin 2 |
| Label `DIR_L` | U_DRV_L pin 3 (DIR) | DIR_L | → Teensy pin 3 |
| Label `MOTOR_L+` | U_DRV_L pin 4 (OUT+) | MOTOR_L+ | Motor terminal |
| Label `MOTOR_L-` | U_DRV_L pin 5 (OUT−) | MOTOR_L- | Motor terminal |
| Label `GND` | U_DRV_L pin 6 (GND) | GND | Ground |

### Wiring Instructions — Right Motor Driver (U_DRV_R → BTS7960)

| Wire From | Wire To | Net Name | Notes |
|---|---|---|---|
| Label `VBAT_FUSED_4` | U_DRV_R pin 1 (VIN) | VBAT_FUSED_4 | 12V from fuse block |
| Label `LPWM_R` | U_DRV_R pin 2 (LPWM) | LPWM_R | → Teensy pin 22 (PWM) |
| Label `RPWM_R` | U_DRV_R pin 3 (RPWM) | RPWM_R | → Teensy pin 20 (DIR) |
| Label `MOTOR_R+` | U_DRV_R pin 4 (OUT+) | MOTOR_R+ | Motor terminal |
| Label `MOTOR_R-` | U_DRV_R pin 5 (OUT−) | MOTOR_R- | Motor terminal |
| Label `BTS_R_EN` | U_DRV_R pin 6 (R_EN) | BTS_R_EN | Enable (tie HIGH or to Teensy) |
| Label `BTS_L_EN` | U_DRV_R pin 7 (L_EN) | BTS_L_EN | Enable (tie HIGH or to Teensy) |
| Label `GND` | U_DRV_R pin 8 (GND) | GND | Ground |

### Wiring Instructions — Teensy 4.1 (U_MCU) Left Side (pins 1–24)

| Teensy Pin | Physical Pin # | Wire To | Net Name |
|---|---|---|---|
| Pin 2 (PWM) | Left row | Label `PWM_L` | PWM_L |
| Pin 3 (DIR) | Left row | Label `DIR_L` | DIR_L |
| Pin 6 (ENC_L_A) | Left row | Label `ENC_L_A` | ENC_L_A |
| Pin 7 (ENC_L_B) | Left row | Label `ENC_L_B` | ENC_L_B |
| GND | Left row | Label `GND` | GND |
| 3V | Left row | #PWR103 (+3V3) | +3V3 |

### Wiring Instructions — Teensy 4.1 (U_MCU) Right Side (pins 25–48)

| Teensy Pin | Physical Pin # | Wire To | Net Name |
|---|---|---|---|
| Pin 10 | Right row | Label `SERVO_J1` | SERVO_J1 |
| Pin 11 | Right row | Label `SERVO_J2` | SERVO_J2 |
| Pin 12 | Right row | Label `SERVO_J3` | SERVO_J3 |
| Pin 13 | Right row | Label `SERVO_J4` | SERVO_J4 |
| Pin 14 | Right row | Label `SERVO_J5` | SERVO_J5 |
| Pin 15 | Right row | Label `SERVO_J6` | SERVO_J6 |
| Pin 18 (ENC_R_B) | Right row | Label `ENC_R_B` | ENC_R_B |
| Pin 19 (ENC_R_A) | Right row | Label `ENC_R_A` | ENC_R_A |
| Pin 20 (DIR_R) | Right row | Label `RPWM_R` | RPWM_R |
| Pin 22 (PWM_R) | Right row | Label `LPWM_R` | LPWM_R |

### Wiring Instructions — Motor Connectors

| Wire From | Wire To | Net Name | Notes |
|---|---|---|---|
| Label `MOTOR_L+` | M_L pin 1 (M1) | MOTOR_L+ | Left motor terminal 1 |
| Label `MOTOR_L-` | M_L pin 2 (M2) | MOTOR_L- | Left motor terminal 2 |
| M_L pin 3 (VCC) | +3V3 or +5V | — | Encoder power (3.3V from Teensy) |
| M_L pin 4 (GND) | GND | GND | Encoder ground |
| Label `ENC_L_A` | M_L pin 5 (OutA) | ENC_L_A | Left encoder channel A |
| Label `ENC_L_B` | M_L pin 6 (OutB) | ENC_L_B | Left encoder channel B |
| Label `MOTOR_R+` | M_R pin 1 (M1) | MOTOR_R+ | Right motor terminal 1 |
| Label `MOTOR_R-` | M_R pin 2 (M2) | MOTOR_R- | Right motor terminal 2 |
| M_R pin 3 (VCC) | +3V3 | — | Encoder power |
| M_R pin 4 (GND) | GND | GND | Encoder ground |
| Label `ENC_R_A` | M_R pin 5 (OutA) | ENC_R_A | Right encoder channel A |
| Label `ENC_R_B` | M_R pin 6 (OutB) | ENC_R_B | Right encoder channel B |

### Wiring Instructions — Servo Signal Connectors

| Wire From | Wire To | Net Name | Notes |
|---|---|---|---|
| Label `SERVO_J1` | SIG_J1 pin 1 | SERVO_J1 | Base servo signal (Teensy pin 10) |
| Label `SERVO_J2` | SIG_J2 pin 1 | SERVO_J2 | Shoulder servo signal (Teensy pin 11) |
| Label `SERVO_J3` | SIG_J3 pin 1 | SERVO_J3 | Elbow servo signal (Teensy pin 12) |
| Label `SERVO_J4` | SIG_J4 pin 1 | SERVO_J4 | Wrist pitch servo signal (Teensy pin 13) |
| Label `SERVO_J5` | SIG_J5 pin 1 | SERVO_J5 | Wrist rotate servo signal (Teensy pin 14) |
| Label `SERVO_J6` | SIG_J6 pin 1 | SERVO_J6 | Gripper servo signal (Teensy pin 15) |

---

## 3. Prototype — Peripherals & Sensors

**Sheet:** `Peripherals_Sensors.kicad_sch`
**Page size:** A3

### Components

| Ref | Value | Description |
|-----|---|---|
| U_IPC | MIC-711 | Advantech MIC-711 IPC / Jetson Orin NX (8-pin connector) |
| U_HUB | USB Hub | 4-port USB hub (4-pin connector) |
| J_TEENSY_USB | Teensy USB | USB connection from Teensy to MIC-711 (1-pin) |
| U_ROUTER | GL.iNet Mango | Travel router for WiFi (3-pin connector) |
| U_CAM | OAK-D Lite | Depth camera (1-pin USB connector) |
| U_LIDAR | RPLIDAR A1M8 | 360° LiDAR scanner (1-pin USB connector) |
| #PWR201 | +12V | Power symbol |
| #PWR202 | GND | Power symbol |
| #PWR203 | +5V | Power symbol |

### Wiring Instructions

| Wire From | Wire To | Net Name | Notes |
|---|---|---|---|
| Label `VBAT_FUSED_3` | U_IPC pin 1 (12V IN) | VBAT_FUSED_3 | 12V power from fuse block |
| Label `GND` | U_IPC pin 8 (GND) | GND | IPC ground |
| U_IPC pin 2 (ETH) | Label `ETHERNET` | ETHERNET | RJ45 to router |
| U_IPC pin 3 (USB 2.0) | Label `USB_2.0` | USB_2.0 | USB 2.0 port |
| U_IPC pin 4 (USB 3.0) | Label `USB_3.0` | USB_3.0 | USB 3.0 port |
| Label `ETHERNET` | U_ROUTER pin 1 (WAN) | ETHERNET | Ethernet to router |
| Label `V_5V_USB` | U_HUB pin 1 (VCC) | V_5V_USB | USB hub power |
| Label `USB_2.0` | U_HUB pin 2 (upstream) | USB_2.0 | Hub upstream to IPC |
| U_HUB pin 3 (port 1) | J_TEENSY_USB pin 1 | — | Direct wire, Teensy USB |
| U_HUB pin 4 (port 2) | U_ROUTER pin 2 (USB power) | — | Router USB power |
| Label `USB_3.0` | U_CAM pin 1 | USB_3.0 | OAK-D on USB 3.0 (MUST be 3.0) |
| U_HUB pin 3 (port 3) | U_LIDAR pin 1 | — | RPLIDAR via USB hub |
| #PWR201 (+12V) | VBAT_FUSED_3 net | +12V | Power flag |
| #PWR203 (+5V) | V_5V_USB net | +5V | Power flag |

---

## 4. Product — Power Distribution & E-Stop

**Sheet:** `Power_Distribution.kicad_sch`
**Page size:** A3

### Components

| Ref | Value | Description |
|-----|---|---|
| J1 | Conn_01x02 | Battery input connector (XT60) |
| SW1 | SW_Push | Emergency stop push button |
| F1 | 30A | Main fuse |
| F4 | 5A | Compute fuse |
| F5 | 2A | Coil fuse |
| F2L | 15A | Left motor fuse |
| F2R | 15A | Right motor fuse |
| F3 | 10A | Compute fuse |
| K1 | G5LE-1A-DC24 | E-stop relay (SPST-NO) |
| D1 | 1N4007 | Flyback diode across relay coil |
| D2 | 1N4007 | Protection diode |
| Q1 | IRLZ44N | N-channel MOSFET for relay drive |
| R1 | R | Gate resistor |
| R2 | R | Pull-down resistor |
| R11 | 1k | Current limiting |
| R12 | 47k | Pull-down |
| U1 | LM5116SD | Synchronous buck controller — 24V→12V |
| L_BUCK1 | 22uH | Buck 1 inductor |
| D_BUCK1 | SS34 | Buck 1 Schottky diode |
| R_FB1A | 40.2k | Buck 1 feedback divider (top) |
| R_FB1B | 3.24k | Buck 1 feedback divider (bottom) |
| C1 | 470uF | Input filter cap |
| C2 | 470uF 25V | Buck 1 output cap |
| C5 | 100nF | Buck 1 decoupling |
| U2 | TPS5430DDA | Step-down converter — 12V→5V |
| L_BUCK2 | 22uH | Buck 2 inductor |
| D_BUCK2 | SS34 | Buck 2 Schottky diode |
| R_FB2A | 53.6k | Buck 2 feedback divider (top) |
| R_FB2B | 15k | Buck 2 feedback divider (bottom) |
| C3 | 470uF 16V | Buck 2 output cap |
| C6 | 100nF | Buck 2 decoupling |
| U3 | AMS1117-3.3 | LDO regulator — 5V→3.3V |
| C4 | 470uF 10V | LDO output cap |
| C7 | 100nF | LDO input decoupling |
| C8 | 10uF | LDO output decoupling |

### Wiring Instructions — Battery & Fusing

| Wire From | Wire To | Net Name | Notes |
|---|---|---|---|
| J1 pin 1 | Label `VBAT` | VBAT | Battery positive (24V nominal) |
| J1 pin 2 | GND symbol | GND | Battery ground |
| Label `VBAT` | SW1 pin 1 | VBAT | E-stop input |
| SW1 pin 2 | F1 pin 1 | — | To main fuse |
| F1 pin 2 | Label `VBAT_MOTOR` | VBAT_MOTOR | Post-fuse motor bus |
| Label `VBAT_MOTOR` | F2L pin 1 | — | Left motor fuse |
| Label `VBAT_MOTOR` | F2R pin 1 | — | Right motor fuse |
| F2L pin 2 | Label `VCC_25V` | VCC_25V | → Left motor driver (Drivers sheet) |
| F2R pin 2 | Label `VCC_25V` | VCC_25V | → Right motor driver (Drivers sheet) |
| Label `VBAT` | F4 pin 1 | — | Compute fuse |
| F4 pin 2 | Label `VBAT_COMPUTE` | VBAT_COMPUTE | To compute buck input |
| Label `VBAT` | F5 pin 1 | — | Coil fuse |
| F5 pin 2 | Label `VBAT_COIL` | VBAT_COIL | To relay coil circuit |

### Wiring Instructions — E-Stop Relay Circuit

**K1 (G5LE-1A) pin map:** Pin 1 = Coil+, Pin 2 = Coil−, Pin 3 = COM, Pin 4 = NO
**Q1 (IRLZ44N) pin map:** Pin 1 = Gate, Pin 2 = Drain, Pin 3 = Source
**D1/D2 (1N4007) pin map:** Pin 1 = Anode (A), Pin 2 = Cathode (K)

| Wire From | Wire To | Net Name | Notes |
|---|---|---|---|
| Label `ESTOP_RELAY_CTRL` | R11 pin 1 | ESTOP_RELAY_CTRL | From STM32 GPIO |
| R11 pin 2 | R12 pin 1 | — | Voltage divider junction |
| R12 pin 1 | Q1 pin 1 | — | MOSFET gate drive |
| R12 pin 2 | GND symbol | GND | Pull-down to ground |
| Q1 pin 3 | GND symbol | GND | MOSFET source |
| Q1 pin 2 | K1 pin 2 | — | MOSFET drain → relay coil− |
| Label `VBAT_COIL` | K1 pin 1 | — | Fused battery → relay coil+ |
| D1 pin 1 | Q1 pin 2 | — | Flyback diode anode → coil low side |
| D1 pin 2 | K1 pin 1 | — | Flyback diode cathode → coil high side |
| Label `VBAT_MOTOR` | K1 pin 3 | — | Power in → relay COM |
| K1 pin 4 | Label `RELAY_COIL_IN` | RELAY_COIL_IN | Relay NO → power out when energized |

### Wiring Instructions — Buck Converter 1 (LM5116, 24V→12V)

**U1 (LM5116) key pins:** VIN, SW, FB, GND, VCC (check symbol for exact pin #s)
**D_BUCK1 (SS34):** Pin 1 = Anode, Pin 2 = Cathode

| Wire From | Wire To | Net Name | Notes |
|---|---|---|---|
| Label `VBAT_COMPUTE` | U1 VIN pin | — | Input voltage |
| C1 pin 1 | U1 VIN pin | — | Input cap |
| C1 pin 2 | GND symbol | GND | Input cap ground |
| U1 SW pin | L_BUCK1 pin 1 | — | Switch node through inductor |
| L_BUCK1 pin 2 | Label `VCC_12V` | VCC_12V | 12V regulated output |
| D_BUCK1 pin 1 | GND symbol | GND | Schottky diode anode |
| D_BUCK1 pin 2 | U1 SW pin | — | Schottky diode cathode → switch node |
| R_FB1A pin 1 | Label `VCC_12V` | — | Feedback top |
| R_FB1A pin 2 | R_FB1B pin 1 | — | Feedback divider mid |
| R_FB1B pin 2 | GND symbol | GND | Feedback bottom |
| R_FB1A pin 2 (junction) | U1 FB pin | — | Feedback to regulator |
| C2 pin 1 | Label `VCC_12V` | — | Output cap |
| C2 pin 2 | GND symbol | GND | |
| C5 pin 1 | U1 VCC pin | — | Decoupling |
| C5 pin 2 | GND symbol | GND | |

### Wiring Instructions — Buck Converter 2 (TPS5430, 12V→5V)

**U2 (TPS5430) key pins:** VIN, PH (switch node), VSENSE (FB), GND, BOOT
**D_BUCK2 (SS34):** Pin 1 = Anode, Pin 2 = Cathode

| Wire From | Wire To | Net Name | Notes |
|---|---|---|---|
| Label `VCC_12V` | U2 VIN pin | — | Input from Buck 1 |
| U2 PH pin | L_BUCK2 pin 1 | — | Switch node through inductor |
| L_BUCK2 pin 2 | Label `VCC_5V` | VCC_5V | 5V regulated output |
| D_BUCK2 pin 1 | GND symbol | GND | Schottky anode |
| D_BUCK2 pin 2 | U2 PH pin | — | Schottky cathode → switch node |
| R_FB2A pin 1 | Label `VCC_5V` | — | Feedback top |
| R_FB2A pin 2 | R_FB2B pin 1 | — | Feedback mid |
| R_FB2B pin 2 | GND symbol | GND | Feedback bottom |
| R_FB2A pin 2 (junction) | U2 VSENSE pin | — | Feedback to regulator |
| C3 pin 1 | Label `VCC_5V` | — | Output cap |
| C3 pin 2 | GND symbol | GND | |
| C6 pin 1 | U2 VIN pin | — | Decoupling |
| C6 pin 2 | GND symbol | GND | |

### Wiring Instructions — LDO (AMS1117, 5V→3.3V)

**U3 (AMS1117-3.3) pin map:** Pin 1 = GND/Adjust, Pin 2 = VOUT, Pin 3 = VIN

| Wire From | Wire To | Net Name | Notes |
|---|---|---|---|
| Label `VCC_5V` | U3 pin 3 | — | VIN input from Buck 2 |
| U3 pin 2 | Label `VCC_3V3` | VCC_3V3 | VOUT 3.3V regulated |
| U3 pin 1 | GND symbol | GND | Ground |
| C4 pin 1 | Label `VCC_3V3` | — | Output cap |
| C4 pin 2 | GND symbol | GND | |
| C7 pin 1 | U3 pin 3 | — | Input decoupling |
| C7 pin 2 | GND symbol | GND | |
| C8 pin 1 | U3 pin 2 | — | Output decoupling |
| C8 pin 2 | GND symbol | GND | |

---

## 5. Product — STM32 MCU

**Sheet:** `STM32_MCU.kicad_sch`
**Page size:** A3

### Components

| Ref | Value | Description |
|-----|---|---|
| U4 | STM32F405RGT6 | Main MCU (64-pin LQFP) |
| Y1 | 8MHz | HSE crystal oscillator |
| C9 | 22pF | Crystal load cap 1 |
| C10 | 22pF | Crystal load cap 2 |
| U_USB | CP2102N | USB-to-UART bridge |
| J_SWD | SWD Header | SWD debug connector (4-pin) |
| J_USB | USB-C | USB-C connector |
| R1 | 10k | BOOT0 pull-down |
| R2 | 10k | BOOT1 pull-down |
| R_I2C_SCL | 4.7k | I2C SCL pull-up to 3.3V |
| R_I2C_SDA | 4.7k | I2C SDA pull-up to 3.3V |
| C_VDD1 | 100nF | VDD decoupling #1 |
| C_VDD_BULK | 4.7uF | VDD bulk decoupling |
| C_VCAP1 | 1uF | VCAP1 filter |
| C_VCAP2 | 1uF | VCAP2 filter |
| C_NRST | 100nF | NRST filter cap |

### Wiring Instructions — Crystal

**Y1 (8MHz crystal):** Pin 1 = OSC_IN side, Pin 2 = OSC_OUT side

| Wire From | Wire To | Net Name | Notes |
|---|---|---|---|
| Y1 pin 1 | U4 PH0 (OSC_IN) | — | HSE input |
| Y1 pin 2 | U4 PH1 (OSC_OUT) | — | HSE output |
| C9 pin 1 | Y1 pin 1 | — | Load cap to OSC_IN |
| C9 pin 2 | GND symbol | GND | |
| C10 pin 1 | Y1 pin 2 | — | Load cap to OSC_OUT |
| C10 pin 2 | GND symbol | GND | |

### Wiring Instructions — STM32 Pin Assignments

| STM32 Pin | Net Label | Direction | Destination |
|---|---|---|---|
| PA5 (SPI1_SCK) | `SPI1_SCK` | Output | → DRV8243 L/R, IMU (Drivers sheet) |
| PA6 (SPI1_MISO) | `SPI1_MISO` | Input | ← DRV8243 L/R, IMU |
| PA7 (SPI1_MOSI) | `SPI1_MOSI` | Output | → DRV8243 L/R, IMU |
| PB0 | `SPI1_CS_DRV_L` | Output | → DRV8243 Left chip select |
| PB1 | `SPI1_CS_DRV_R` | Output | → DRV8243 Right chip select |
| PB2 | `SPI1_CS_IMU` | Output | → ICM-42688-P chip select |
| PA11 (CAN1_RX) | `CAN1_RX` | Input | ← SN65HVD230 #1 (arm CAN) |
| PA12 (CAN1_TX) | `CAN1_TX` | Output | → SN65HVD230 #1 |
| PB5 (CAN2_TX) | `CAN2_TX` | Output | → SN65HVD230 #2 (sensor CAN) |
| PB6 (CAN2_RX) | `CAN2_RX` | Input | ← SN65HVD230 #2 |
| PA2 (USART2_TX) | `USART2_TX` | Output | → CP2102N RXD, Jetson (Connectors sheet) |
| PA3 (USART2_RX) | `USART2_RX` | Input | ← CP2102N TXD, Jetson |
| PB8 (I2C1_SCL) | `I2C1_SCL` | Bidir | ↔ INA226 monitors (Drivers sheet) |
| PB9 (I2C1_SDA) | `I2C1_SDA` | Bidir | ↔ INA226 monitors |
| PC0 (ENC_L_A) | `ENC_L_A` | Input | ← Left encoder A (Drivers sheet) |
| PC1 (ENC_L_B) | `ENC_L_B` | Input | ← Left encoder B |
| PC2 (ENC_R_A) | `ENC_R_A` | Input | ← Right encoder A |
| PC3 (ENC_R_B) | `ENC_R_B` | Input | ← Right encoder B |
| PA8 | `ESTOP_RELAY_CTRL` | Output | → Relay MOSFET gate (Power sheet) |

### Wiring Instructions — USB Bridge (CP2102N)

**U_USB (CP2102N) key pins:** Check symbol for exact pin #s — TXD, RXD, D+, D−, VDD, GND

| Wire From | Wire To | Net Name | Notes |
|---|---|---|---|
| U_USB TXD pin | Label `USART2_RX` | USART2_RX | CP2102N TX → STM32 RX |
| U_USB RXD pin | Label `USART2_TX` | USART2_TX | STM32 TX → CP2102N RX |
| U_USB D+ pin | J_USB pin 2 | — | USB data+ |
| U_USB D− pin | J_USB pin 3 | — | USB data− |
| U_USB VDD pin | +3.3V symbol | — | 3.3V power |
| U_USB GND pin | GND symbol | GND | |
| J_USB pin 1 | +5V symbol | — | USB VBUS 5V |
| J_USB pin 4 | GND symbol | GND | |

### Wiring Instructions — Decoupling & Boot

| Wire From | Wire To | Net Name | Notes |
|---|---|---|---|
| C_VDD1 pin 1 | +3.3V symbol | VCC_3V3 | Place close to U4 VDD pin |
| C_VDD1 pin 2 | GND symbol | GND | |
| C_VDD_BULK pin 1 | +3.3V symbol | VCC_3V3 | Bulk cap near MCU |
| C_VDD_BULK pin 2 | GND symbol | GND | |
| C_VCAP1 pin 1 | U4 VCAP1 pin | — | Internal regulator filter |
| C_VCAP1 pin 2 | GND symbol | GND | |
| C_VCAP2 pin 1 | U4 VCAP2 pin | — | Internal regulator filter |
| C_VCAP2 pin 2 | GND symbol | GND | |
| C_NRST pin 1 | U4 NRST pin | — | Reset filter |
| C_NRST pin 2 | GND symbol | GND | |
| R1 pin 1 | U4 BOOT0 pin | — | BOOT0 pull-down |
| R1 pin 2 | GND symbol | GND | Normal boot from flash |
| R2 pin 1 | U4 BOOT1 pin | — | BOOT1 pull-down |
| R2 pin 2 | GND symbol | GND | |
| R_I2C_SCL pin 1 | +3.3V symbol | — | I2C pull-up |
| R_I2C_SCL pin 2 | Label `I2C1_SCL` | I2C1_SCL | |
| R_I2C_SDA pin 1 | +3.3V symbol | — | I2C pull-up |
| R_I2C_SDA pin 2 | Label `I2C1_SDA` | I2C1_SDA | |

### SWD Debug Header

| J_SWD Pin | Wire To | Notes |
|---|---|---|
| Pin 1 | +3.3V symbol | Target voltage reference |
| Pin 2 | U4 PA13 pin | SWDIO debug data |
| Pin 3 | U4 PA14 pin | SWCLK debug clock |
| Pin 4 | GND symbol | Ground |

---

## 6. Product — Motor Drivers, CAN, IMU & Power Monitors

**Sheet:** `Drivers_CAN_IMU_Power.kicad_sch`
**Page size:** A3

### Components

| Ref | Value | Description |
|-----|---|---|
| U5L | DRV8243SQDGQRQ1 | SPI-controlled H-bridge — Left motor |
| U5R | DRV8243SQDGQRQ1 | SPI-controlled H-bridge — Right motor |
| U6A | SN65HVD230DR | CAN transceiver #1 (arm bus) |
| U6S | SN65HVD230DR | CAN transceiver #2 (sensor bus) |
| U7 | ICM-42688-P | 6-axis IMU (SPI) |
| U8 | INA226AIDGST | Current/power monitor — Motor bus |
| U9 | INA226AIDGST | Current/power monitor — 12V compute |
| U10 | INA226AIDGST | Current/power monitor — 5V servo |
| J_CAN_ARM | CAN Arm | CAN bus connector to arm controller |
| J_MOTOR_L | Motor L | Left motor power connector (3-pin) |
| J_MOTOR_R | Motor R | Right motor power connector (3-pin) |
| J_ENC_L | Encoder L | Left encoder connector (4-pin) |
| J_ENC_R | Encoder R | Right encoder connector (4-pin) |
| C11L/C12L/C13L | Decoupling | DRV8243 Left bypass caps |
| C11R/C12R/C13R | Decoupling | DRV8243 Right bypass caps |
| TVS1L/TVS1R | SMBJ28A | TVS protection diodes |
| R3L/R3R | 10mΩ | Current sense resistors |
| R4A/R4S | 120Ω | CAN bus termination resistors |
| C14A/C14S | 100nF | CAN transceiver decoupling |
| R5 | 4.7k | IMU CS pull-up |
| C15/C16 | 100nF/1uF | IMU decoupling |
| R6/R7/R8 | 10mΩ | INA226 shunt resistors |
| C17/C18/C19 | 100nF | INA226 decoupling |

### Wiring Instructions — DRV8243 Left (U5L)

**U5L (DRV8243) pin names are on the symbol.** Use the pin names shown on the IC to find the correct pin #.

| Wire From | Wire To | Net Name | Notes |
|---|---|---|---|
| Label `MOTOR_PWR_L` | U5L VM pin | MOTOR_PWR_L | Motor power input (24V) |
| Label `SPI1_SCK` | U5L SCLK pin | SPI1_SCK | SPI clock from STM32 |
| Label `SPI1_MOSI` | U5L SDI pin | SPI1_MOSI | SPI data in |
| Label `SPI1_MISO` | U5L SDO pin | SPI1_MISO | SPI data out |
| Label `SPI1_CS_DRV_L` | U5L nSCS pin | SPI1_CS_DRV_L | Chip select (active low) |
| U5L OUT1 pin | J_MOTOR_L pin 1 | — | Motor terminal 1 |
| U5L OUT2 pin | J_MOTOR_L pin 2 | — | Motor terminal 2 |
| J_MOTOR_L pin 3 | GND symbol | GND | Motor ground |
| C11L pin 1 | U5L DVDD pin | — | Digital decoupling |
| C11L pin 2 | GND symbol | GND | |
| C12L pin 1 | U5L VM pin | — | Motor supply decoupling |
| C12L pin 2 | GND symbol | GND | |
| C13L pin 1 | U5L AVDD pin | — | Analog decoupling |
| C13L pin 2 | GND symbol | GND | |
| TVS1L pin 1 | U5L VM pin | — | TVS anode to VM |
| TVS1L pin 2 | GND symbol | — | TVS cathode to GND |
| R3L pin 1 | U5L GND pin | — | Sense resistor (IC side) |
| R3L pin 2 | GND symbol | — | Sense resistor (ground side) |

### Wiring Instructions — DRV8243 Right (U5R)

*Same topology as U5L, substituting:*
- `MOTOR_PWR_R` for VM
- `SPI1_CS_DRV_R` for nSCS
- J_MOTOR_R for motor connector
- C11R/C12R/C13R, TVS1R, R3R for passives

### Wiring Instructions — CAN Transceivers

**U6A/U6S (SN65HVD230) pin names are on the symbol:** TXD, RXD, CANH, CANL, VCC, GND, Rs

| Wire From | Wire To | Net Name | Notes |
|---|---|---|---|
| Label `CAN1_TX` | U6A TXD pin | CAN1_TX | From STM32 CAN1_TX |
| Label `CAN1_RX` | U6A RXD pin | CAN1_RX | To STM32 CAN1_RX |
| U6A CANH pin | Label `CAN_H_ARM` | CAN_H_ARM | CAN bus high |
| U6A CANL pin | Label `CAN_L_ARM` | CAN_L_ARM | CAN bus low |
| U6A VCC pin | +3.3V symbol | — | 3.3V power |
| U6A GND pin | GND symbol | GND | |
| R4A pin 1 | U6A CANH pin | — | 120Ω termination |
| R4A pin 2 | U6A CANL pin | — | |
| C14A pin 1 | U6A VCC pin | — | Decoupling |
| C14A pin 2 | GND symbol | GND | |
| Label `CAN_H_ARM` | J_CAN_ARM pin 1 | CAN_H_ARM | To arm CAN connector |
| Label `CAN_L_ARM` | J_CAN_ARM pin 2 | CAN_L_ARM | |
| J_CAN_ARM pin 3 | GND symbol | GND | CAN ground |
| Label `CAN2_TX` | U6S TXD pin | CAN2_TX | From STM32 CAN2_TX |
| Label `CAN2_RX` | U6S RXD pin | CAN2_RX | To STM32 CAN2_RX |
| *(U6S: same wiring as U6A — R4S for termination, C14S for decoupling)* | | | |

### Wiring Instructions — IMU (U7 ICM-42688-P)

**U7 (ICM-42688-P) pin names are on the symbol:** SCLK, SDI, SDO, nCS, VDD, VDDIO, GND

| Wire From | Wire To | Net Name | Notes |
|---|---|---|---|
| Label `SPI1_SCK` | U7 SCLK pin | SPI1_SCK | SPI clock |
| Label `SPI1_MOSI` | U7 SDI pin | SPI1_MOSI | SPI data in |
| Label `SPI1_MISO` | U7 SDO pin | SPI1_MISO | SPI data out |
| Label `SPI1_CS_IMU` | U7 nCS pin | SPI1_CS_IMU | Chip select |
| U7 VDD pin | +3.3V symbol | — | Power |
| U7 GND pin | GND symbol | GND | |
| C15 pin 1 | U7 VDD pin | — | Decoupling |
| C15 pin 2 | GND symbol | GND | |
| C16 pin 1 | U7 VDDIO pin | — | IO voltage decoupling |
| C16 pin 2 | GND symbol | GND | |
| R5 pin 1 | +3.3V symbol | — | CS pull-up (deselect) |
| R5 pin 2 | U7 nCS pin | — | |

### Wiring Instructions — INA226 Power Monitors

**U8/U9/U10 (INA226) pin names on symbol:** IN+, IN−, VS, SCL, SDA, A0, A1, GND, ALERT

| Monitor | Shunt R | Decoupling C | Monitored Bus | I2C Addr | Measurement |
|---|---|---|---|---|---|
| U8 | R6 (10mΩ) | C17 (100nF) | `VCC_25V` bus | A0=GND, A1=GND (0x40) | Motor bus current |
| U9 | R7 (10mΩ) | C18 (100nF) | `VCC_12V` bus | A0=VS, A1=GND (0x41) | Compute current |
| U10 | R8 (10mΩ) | C19 (100nF) | `VCC_5V` bus | A0=GND, A1=VS (0x44) | Servo current |

*For each INA226 (example using U8/R6/C17):*

| Wire From | Wire To | Notes |
|---|---|---|
| R6 pin 1 | Bus power in (high side) | Shunt in series with bus |
| R6 pin 2 | Bus power out (load side) | |
| U8 IN+ pin | R6 pin 1 | Sense high side |
| U8 IN− pin | R6 pin 2 | Sense low side |
| U8 VS pin | +3.3V symbol | Supply voltage |
| U8 SCL pin | Label `I2C1_SCL` | I2C clock |
| U8 SDA pin | Label `I2C1_SDA` | I2C data |
| U8 GND pin | GND symbol | |
| U8 ALERT pin | *(leave NC or add no-connect flag)* | Optional interrupt |
| C17 pin 1 | U8 VS pin | Decoupling |
| C17 pin 2 | GND symbol | |

### Wiring Instructions — Encoder Connectors

| Wire From | Wire To | Net Name | Notes |
|---|---|---|---|
| J_ENC_L pin 1 | +3.3V symbol | — | Encoder power (3.3V) |
| J_ENC_L pin 2 | GND symbol | GND | |
| J_ENC_L pin 3 | Label `ENC_L_A` | ENC_L_A | → STM32 encoder input |
| J_ENC_L pin 4 | Label `ENC_L_B` | ENC_L_B | |
| J_ENC_R pin 1 | +3.3V symbol | — | |
| J_ENC_R pin 2 | GND symbol | GND | |
| J_ENC_R pin 3 | Label `ENC_R_A` | ENC_R_A | |
| J_ENC_R pin 4 | Label `ENC_R_B` | ENC_R_B | |

---

## 7. Product — Connectors, LEDs, USB & Peripherals

**Sheet:** `Connectors_LED_USB.kicad_sch`
**Page size:** A3

### Components

| Ref | Value | Description |
|-----|---|---|
| U11 | PT4115 | LED constant-current driver |
| L_LED | 22uH | LED driver inductor |
| D_LED | SS34 | LED driver diode |
| R9 | 470Ω | LED current set resistor |
| R10 | 0.1Ω | LED sense resistor |
| C20 | 100uF | LED driver cap |
| J_LED_WORK | Work Light | High-power work light connector |
| J_LED_STATUS | LED Status | RGB/status LED connector (3-pin) |
| J_JETSON | Jetson | Jetson communication connector (4-pin: TX, RX, VCC, GND) |
| J_LIDAR | LiDAR | RPLIDAR connector (4-pin: USB D+, D−, VCC, GND) |
| J_CAMERA | Camera | OAK-D Lite connector (2-pin: USB, GND) |
| J_BUMPER_FL | Bumper FL | Front-left bumper switch (2-pin) |
| J_BUMPER_FR | Bumper FR | Front-right bumper switch |
| J_BUMPER_RL | Bumper RL | Rear-left bumper switch |
| J_BUMPER_RR | Bumper RR | Rear-right bumper switch |

### Wiring Instructions — LED Driver (PT4115)

**U11 (PT4115) pin names on symbol:** VIN, SW, DIM, CSN, GND
**D_LED (SS34):** Pin 1 = Anode, Pin 2 = Cathode

| Wire From | Wire To | Net Name | Notes |
|---|---|---|---|
| Label `VCC_12V` | L_LED pin 1 | VCC_12V | 12V input |
| L_LED pin 2 | U11 VIN pin | — | Through inductor |
| U11 SW pin | D_LED pin 2 | — | Switch node → diode cathode |
| D_LED pin 1 | GND symbol | GND | Diode anode to ground |
| U11 DIM pin | R9 pin 1 | — | Dimming/enable |
| R9 pin 2 | +5V symbol | — | Pull-up for always-on |
| U11 CSN pin | R10 pin 1 | — | Current sense |
| R10 pin 2 | GND symbol | GND | |
| U11 SW pin | J_LED_WORK pin 1 | — | LED anode (through inductor) |
| J_LED_WORK pin 2 | R10 pin 1 | — | LED cathode → sense R |
| C20 pin 1 | U11 VIN pin | — | Input filtering |
| C20 pin 2 | GND symbol | GND | |

### Wiring Instructions — Status LED

| Wire From | Wire To | Notes |
|---|---|---|
| J_LED_STATUS pin 1 | +5V symbol | LED power |
| J_LED_STATUS pin 2 | *(STM32 GPIO via net label)* | Control signal |
| J_LED_STATUS pin 3 | GND symbol | |

### Wiring Instructions — Communication Connectors

| Wire From | Wire To | Net Name | Notes |
|---|---|---|---|
| Label `USART2_TX` | J_JETSON pin 1 | USART2_TX | STM32 TX → Jetson RX |
| Label `USART2_RX` | J_JETSON pin 2 | USART2_RX | Jetson TX → STM32 RX |
| J_JETSON pin 3 | +5V symbol | — | Jetson power |
| J_JETSON pin 4 | GND symbol | GND | |
| J_LIDAR pin 1 | +5V symbol | — | RPLIDAR power |
| J_LIDAR pin 2 | GND symbol | GND | |
| J_LIDAR pin 3 | *(USB D+)* | — | USB data |
| J_LIDAR pin 4 | *(USB D−)* | — | USB data |
| J_CAMERA pin 1 | +5V symbol | — | OAK-D power (via USB) |
| J_CAMERA pin 2 | GND symbol | GND | |

### Wiring Instructions — Bumper Switches

| Wire From | Wire To | Net Name | Notes |
|---|---|---|---|
| J_BUMPER_FL pin 1 | Label `BUMPER_FL` | BUMPER_FL | → STM32 GPIO (active low) |
| J_BUMPER_FL pin 2 | GND symbol | GND | Normally open switch |
| J_BUMPER_FR pin 1 | Label `BUMPER_FR` | BUMPER_FR | |
| J_BUMPER_FR pin 2 | GND symbol | GND | |
| J_BUMPER_RL pin 1 | Label `BUMPER_RL` | BUMPER_RL | |
| J_BUMPER_RL pin 2 | GND symbol | GND | |
| J_BUMPER_RR pin 1 | Label `BUMPER_RR` | BUMPER_RR | |
| J_BUMPER_RR pin 2 | GND symbol | GND | |

---

## 8. Cross-Sheet Net Label Reference

Labels with the same name across sheets are electrically connected in KiCad (within the same hierarchical project). Here's the complete cross-sheet net map:

### Prototype Cross-Sheet Nets

| Net Label | Sheet 1 (Source) | Sheet 2 (Destination) | Description |
|---|---|---|---|
| `VBAT_FUSED_1` | Power Distribution (F1 out) | Peripherals (MIC-711 power) | Compute power rail |
| `VBAT_FUSED_2` | Power Distribution (F2 out) | Teensy (MD10C L power) | Left motor driver power |
| `VBAT_FUSED_3` | Power Distribution (F3 out) | Peripherals (MIC-711/router) | Peripheral power rail |
| `VBAT_FUSED_4` | Power Distribution (F4 out) | Teensy (BTS7960 R power) | Right motor driver power |
| `GND` | All sheets | All sheets | Common ground |
| `V_SERVO` | Power Distribution (buck out) | — (stays on same sheet) | 6.8V servo bus |
| `SERVO_J1`–`SERVO_J6` | Teensy (MCU pins) | — (stays on same sheet) | Servo signal wires |
| `ENC_L_A/B`, `ENC_R_A/B` | Teensy (MCU pins ↔ motor connectors) | — | Encoder signals |
| `PWM_L`, `DIR_L` | Teensy (MCU pins ↔ MD10C) | — | Left motor control |
| `LPWM_R`, `RPWM_R` | Teensy (MCU pins ↔ BTS7960) | — | Right motor control |

### Product Cross-Sheet Nets

| Net Label | Sheets Connected | Description |
|---|---|---|
| `VBAT` | Power Distribution | Raw battery voltage |
| `VCC_25V` | Power Dist → Drivers | Motor bus (post-fuse) |
| `VCC_12V` | Power Dist → Drivers, Connectors | 12V regulated rail |
| `VCC_5V` | Power Dist → Drivers, Connectors | 5V regulated rail |
| `VCC_3V3` | Power Dist → STM32, Drivers | 3.3V regulated rail |
| `GND` | All 4 sheets | Common ground |
| `SPI1_SCK` | STM32 → Drivers (DRV8243 L/R, IMU) | SPI clock bus |
| `SPI1_MOSI` | STM32 → Drivers | SPI data out |
| `SPI1_MISO` | STM32 ← Drivers | SPI data in |
| `SPI1_CS_DRV_L` | STM32 → Drivers (U5L) | Left driver select |
| `SPI1_CS_DRV_R` | STM32 → Drivers (U5R) | Right driver select |
| `SPI1_CS_IMU` | STM32 → Drivers (U7) | IMU select |
| `CAN1_TX` | STM32 → Drivers (U6A) | CAN1 transmit |
| `CAN1_RX` | STM32 ← Drivers (U6A) | CAN1 receive |
| `CAN2_TX` | STM32 → Drivers (U6S) | CAN2 transmit |
| `CAN2_RX` | STM32 ← Drivers (U6S) | CAN2 receive |
| `I2C1_SCL` | STM32 ↔ Drivers (INA226 ×3) | I2C clock |
| `I2C1_SDA` | STM32 ↔ Drivers (INA226 ×3) | I2C data |
| `USART2_TX` | STM32 → Connectors (Jetson) | UART transmit |
| `USART2_RX` | STM32 ← Connectors (Jetson) | UART receive |
| `ESTOP_RELAY_CTRL` | STM32 → Power Dist (relay circuit) | E-stop control GPIO |
| `ENC_L_A/B` | STM32 ← Drivers (encoder connectors) | Left encoder |
| `ENC_R_A/B` | STM32 ← Drivers (encoder connectors) | Right encoder |
| `BUMPER_FL/FR/RL/RR` | Connectors → (to STM32 via label) | Bumper switch inputs |
| `MOTOR_PWR_L` | Drivers (U5L VM) | Left motor power in |
| `MOTOR_PWR_R` | Drivers (U5R VM) | Right motor power in |
| `CAN_H_ARM` / `CAN_L_ARM` | Drivers (U6A ↔ J_CAN_ARM) | CAN differential pair |

---

## Quick Reference: KiCad Wiring Tips

1. **Start a wire:** Hover over a pin or label endpoint, press `W`
2. **End a wire:** Click on the destination pin or label
3. **Net labels auto-connect:** Two labels with the same name on the same sheet (or across hierarchical sub-sheets) are electrically connected — no wire needed between them
4. **Add a net label:** Press `L`, type the net name exactly as shown above
5. **Add a power symbol:** Press `P`, search for `+12V`, `GND`, `+3V3`, `+5V`, `PWR_FLAG`
6. **Run ERC:** After wiring, go to **Inspect → Electrical Rules Checker** to verify all connections
7. **Junction dots:** If a wire crosses another wire or T-connects, KiCad should auto-add a junction dot. If not, press `J` to manually add one
8. **No-connect flags:** For unused IC pins, press `Q` to add a no-connect flag (X symbol) to suppress ERC warnings

---

*Generated for RECLAIM — MSE 4499 Capstone, Western University*
*Last updated: 2026-04-11*

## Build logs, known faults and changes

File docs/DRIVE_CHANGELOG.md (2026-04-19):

# RECLAIM Drive System — Changelog & Tracking

All changes to the drive/tracking system. Updated after every edit session.

---

## Files We Own

| File | Location | Description |
|---|---|---|
| `waste_tracker.py` | `reclaim_ws/src/reclaim_bringup/reclaim_bringup/` | V1 — own camera, original visual servoing |
| `waste_tracker_v2.py` | same | V2 experimental — stop-look-drive (not used) |
| `waste_tracker_trt.py` | same | TRT V1 — polls TRT server, conservative 10fps tuning |
| `waste_tracker_trt_v2.py` | same | TRT V2 — 30fps optimized, P-only, diagnostics |
| `teensy_bridge.py` | `reclaim_ws/src/reclaim_control/reclaim_control/` | Bridge between ROS2 cmd_vel and Teensy serial |
| `teensy_bridge.yaml` | `reclaim_ws/src/reclaim_control/config/` | Bridge config (calibrated wheel params) |
| `waste_tracker.yaml` | `reclaim_ws/src/reclaim_bringup/config/` | Tracker YAML config |
| `camera_detect_trt.py` | `reclaim_ws/tests/` | TRT camera server (friend's, we changed DEPTH_MAX only) |
| `diag_monitor.py` | repo root | Mac-side UDP diagnostic receiver |
| `sync.sh` | repo root | Rsync wrapper (updated to exclude URDF/tests/models) |
| `MANUAL_TEST_GUIDE.md` | repo root | Manual commands for starting/stopping/testing |

## Files Friend Owns (DO NOT MODIFY without coordinating)

| File | Description |
|---|---|
| `camera_detect_trt.py` | TRT camera server — Python 3.8, TensorRT, 30fps |
| `pick_and_place.py` | MoveIt2 arm pickup pipeline |
| `reclaim_arm_moveit_config/` | Arm URDF, MoveIt config, calibration |
| `reclaim_servo_hardware/` | Servo hardware interface |

---

## Current Active Version: `waste_tracker_trt_v2.py`

### Architecture
```
TRT Server (Python 3.8, port 8081)     waste_tracker_trt_v2 (Python 3.11, ROS2)
  OAK-D camera (640x480)                  Polls HTTP /detection at 30Hz
  YOLO TensorRT @ 30fps          →         Bbox EMA smoothing
  Stereo depth (burst 5 frames)            Kalman filter (4-state)
  Best detection JSON                      P-only controller
  MJPEG stream :8081/stream               Sinusoidal ramp + smooth taper
                                           cmd_vel → Teensy bridge → motors
                                           UDP diagnostics → Mac :9999
```

### Current Tuning Parameters (TRT V2)

| Parameter | Value | Notes |
|---|---|---|
| poll_rate_hz | 30 | Matches TRT server frame rate |
| tick_timer | 33ms | ~30Hz |
| Kp | 0.0012 | P-only, no I/D |
| Ki | 0.0 | Disabled — causes windup |
| Kd | 0.0 | Disabled — amplifies noise |
| EMA alpha | 0.45 | Fast response for clean 30fps data |
| ramp_rate | 0.6 rad/s^2 | Compensates for 3x tick rate |
| deadband | 0.015 | Smooth taper (quadratic fade) |
| bbox_alpha | 0.5 | Bbox center EMA smoothing |
| Kalman Q | 2.0 | Process noise (tighter model) |
| Kalman R | 10.0 | Measurement noise (trust 30fps) |
| lost_threshold | 30 frames | 1 second at 30fps |
| det_hold_max | 4 frames | ~133ms hold during gaps |
| confirm_threshold | 3 frames | With gap tolerance (3 miss allowed) |
| scan_confirm_conf | 0.30 | Lower for 30fps (was 0.35) |
| TURN clamp | +/-0.12 rad/s | Max rotation speed during centering |
| APPROACH clamp | +/-0.10 rad/s | Max correction during approach |
| Coast clamp | +/-0.08 rad/s | Max during Kalman prediction |
| approach_stop_dist | 400mm | Switch to ALIGN |
| approach_max_v | 0.12 m/s | Max forward speed |
| scan_vel | 0.3 rad/s | Rotation speed during scan |

### Ground Filtering (floor-only detection)

| Filter | SCAN | Tracking (TURN/APPROACH/ALIGN) |
|---|---|---|
| Image position (cy_px) | Bottom 75% (cy > 0.25*H) | Bottom 80% (cy > 0.20*H) |
| Max depth | 2500mm | 3000mm |
| Max bbox area | 25% of image | 40% of image |
| Min bbox area | 0.2% of image | 0.3% of image |
| TRT server depth range | 150-3000mm | same |

---

## Change Log

### Session: March 24, 2026

#### waste_tracker.py (V1) — Local + MIC-711
- [x] Replaced hard angular deadband with smooth quadratic taper
- [x] Added sinusoidal ramp limiter (S-curve acceleration)
- [x] Added ByteTrack persistent tracking via model.track() with fallback to model()
- [x] Track ID matching priority in _find_target_in_detections()
- [x] Locked target highlighted cyan in debug feed
- [x] Reset tracked_id on rescan and scan entry
- [x] Synced to MIC-711 and built

#### waste_tracker_trt.py (TRT V1) — Local + MIC-711
- [x] Created from V1, adapted for HTTP polling of TRT server
- [x] Fixed distance_mm to use cam_z (was base_link transform, only valid at arm home pose)
- [x] Fixed bearing_rad to use cam_x/cam_z
- [x] Friend cleaned: removed dead camera_to_robot(), get_depth_for_bbox(), determine_grip(), build_pickup_commands()
- [x] PICK publishes to /pickup_request topic instead of raw serial
- [x] drive_only=True default
- [x] Uploaded to MIC-711, entry point added, built

#### waste_tracker_trt_v2.py (TRT V2) — Local + MIC-711
- [x] P-only controller (dropped Ki, Kd)
- [x] Kp 0.0010 → 0.0012
- [x] EMA alpha 0.18 → 0.45
- [x] Ramp rate 0.3 → 0.6
- [x] Deadband 0.02 → 0.015
- [x] Kalman Q 3.0 → 2.0, R 25.0 → 10.0
- [x] Poll rate 20Hz → 30Hz
- [x] Tick timer 50ms → 33ms
- [x] pid_dt 0.05 → 0.033
- [x] target_lost_threshold 50 → 30
- [x] Added bbox EMA smoothing (alpha=0.5)
- [x] Added detection hold (4 frames / 133ms)
- [x] Added confirmation gap tolerance (3 miss frames)
- [x] Lowered scan confirm conf 0.35 → 0.30
- [x] Added sinusoidal approach speed curve
- [x] Added UDP diagnostics to Mac (port 9999)
- [x] Added CSV tuning log (/tmp/tracker_tuning.csv)
- [x] Added parameter snapshot (/tmp/tracker_tuning_params.txt)
- [x] Added per-run performance stats + summary
- [x] Added state duration tracking
- [x] Added detection rate tracking (rolling 1s window)
- [x] Uploaded to MIC-711, entry point added, built
- [x] Added ground filtering (floor-only, no background objects)
- [x] Aspect ratio filter for non-floor objects
- [x] smooth_angular dt default updated 0.05 → 0.033

#### camera_detect_trt.py — Local + MIC-711
- [x] DEPTH_MAX_MM 600 → 3000 (for driving range, was arm-only)
- [x] Uploaded to MIC-711

#### teensy_bridge.py — Local + MIC-711
- [x] Serial auto-reconnect after 20 consecutive timeouts
- [x] Heading hold Kp 1.0 → 2.0, threshold 0.01 → 0.02 rad/s
- [x] Odom rate 20Hz → 10Hz

#### sync.sh — Local only
- [x] Added --exclude for *.urdf, urdf/, tests/, test/, models/, maps/

#### diag_monitor.py — Local only (Mac tool)
- [x] Created: UDP receiver, color-coded dashboard
- [x] Visual offset bar
- [x] Auto-saves to .jsonl for post-analysis

#### MANUAL_TEST_GUIDE.md — Local + MIC-711
- [x] Rewritten with fast start/stop commands
- [x] Added rescan command
- [x] Added Foxglove instructions
- [x] Added tuning reference tables

---

## Known Issues

| Issue | Status | Notes |
|---|---|---|
| Castor scrub during in-place rotation | Open | Hardware fix: single center castor, or pivot turns |
| Encoders/odom not confirmed working under load | Open | TICKS response may fail during SETVEL contention |
| Detection range ~1.2m typical (want 2-2.5m) | Partially fixed | TRT 30fps + lower conf should help, DEPTH_MAX raised to 3000 |
| Residual jerkiness in corrections | Improved | Smooth taper + sinusoidal ramp + P-only should eliminate most |
| TRT server caches last detection | Fixed | 500ms timeout in server + 1s age check in tracker |
| Zombie processes after kill | Mitigated | ESTOP command, explicit pkill patterns |

## Upcoming / Ideas

- [ ] Test TRT V2 with 30fps pipeline end-to-end
- [ ] Pivot turns for scanning (one wheel stopped)
- [ ] Nav2 integration for search area + smooth path planning
- [ ] Encoder accuracy verification (mark-on-wheel test)
- [ ] Tune TRT server --conf to 0.15 (let tracker do filtering)
- [ ] Add track_id to TRT server API (model.track())

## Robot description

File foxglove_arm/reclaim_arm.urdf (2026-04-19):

<?xml version="1.0" encoding="utf-8"?>
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
<robot name="reclaim_arm">
  <link name="base_link">
    <inertial>
      <origin xyz="0.00060581 -0.001246 -0.046464" rpy="0 0 0" />
      <mass value="0.07337" />
      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
    </inertial>
    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
  </link>
  <link name="shoulder_link">
    <inertial>
      <origin xyz="0.00046002 -0.0098996 0.01241" rpy="0 0 0" />
      <mass value="0.037034" />
      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
    </inertial>
    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
  </link>
  <joint name="base_joint" type="revolute">
    <origin xyz="0 0 0" rpy="0 0 0" />
    <parent link="base_link" />
    <child link="shoulder_link" />
    <axis xyz="0 0 1" />
    <limit lower="-1.953" upper="3.230" effort="10" velocity="2" />
  </joint>
  <link name="upper_arm_link">
    <inertial>
      <origin xyz="1.3297E-14 -0.011444 0.052" rpy="0 0 0" />
      <mass value="0.016627" />
      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
    </inertial>
    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
  </link>
  <joint name="shoulder_joint" type="revolute">
    <origin xyz="0.01 0 0.013402" rpy="0 0 0" />
    <parent link="shoulder_link" />
    <child link="upper_arm_link" />
    <axis xyz="0 -1 0" />
    <limit lower="-2.073" upper="1.597" effort="15" velocity="2" />
  </joint>
  <link name="forearm_link">
    <inertial>
      <origin xyz="0.0013458 -0.010048 0.074887" rpy="0 0 0" />
      <mass value="0.087067" />
      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
    </inertial>
    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
  </link>
  <joint name="elbow_joint" type="revolute">
    <origin xyz="0 0 0.104" rpy="0 0 0" />
    <parent link="upper_arm_link" />
    <child link="forearm_link" />
    <axis xyz="0 1 0" />
    <limit lower="-1.508" upper="2.497" effort="10" velocity="2" />
  </joint>
  <link name="wrist_pitch_link">
    <inertial>
      <origin xyz="-0.024668 -0.011695 0.043013" rpy="0 0 0" />
      <mass value="0.10081" />
      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
    </inertial>
    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
  </link>
  <joint name="wrist_pitch_joint" type="revolute">
    <origin xyz="0 0 0.147" rpy="0 0 0" />
    <parent link="forearm_link" />
    <child link="wrist_pitch_link" />
    <axis xyz="0 -1 0" />
    <limit lower="-1.932" upper="0.872" effort="10" velocity="2" />
  </joint>
  <link name="tool0">
    <inertial>
      <origin xyz="0.010754 -0.0010765 0.39245" rpy="0 0 0" />
      <mass value="0.037311" />
      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
    </inertial>
    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
  </link>
  <joint name="wrist_to_tool0" type="fixed">
    <origin xyz="0 0 0.150" rpy="0 0 0" />
    <parent link="wrist_pitch_link" />
    <child link="tool0" />
    <axis xyz="0 0 0" />
  </joint>
  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
  <link name="gripper_link">
    <inertial>
      <origin xyz="0 0 0.02" rpy="0 0 0"/>
      <mass value="0.142"/>
      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
    </inertial>
  </link>
  <joint name="gripper_joint" type="revolute">
    <origin xyz="0 0 0" rpy="0 0 0"/>
    <parent link="tool0"/>
    <child link="gripper_link"/>
    <axis xyz="0 0 1"/>
    <limit lower="0.0" upper="0.836" effort="5" velocity="2"/>
  </joint>

  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
  <link name="camera_link">
    <inertial>
      <origin xyz="0 0 0" rpy="0 0 0"/>
      <mass value="0.061"/>
      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
    </inertial>
  </link>
  <joint name="wrist_to_camera" type="fixed">
    <origin xyz="-0.068 -0.012 0.064" rpy="0 0 0"/>
    <parent link="wrist_pitch_link"/>
    <child link="camera_link"/>
  </joint>

  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
  <link name="camera_optical_frame"/>
  <joint name="camera_to_optical" type="fixed">
    <origin xyz="0 0 0" rpy="0 0 -1.5708"/>
    <parent link="camera_link"/>
    <child link="camera_optical_frame"/>
  </joint>

  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
  <ros2_control name="servo_hardware" type="system">
    <hardware>
      <plugin>reclaim_servo_hardware/ServoHardwareInterface</plugin>
      <param name="serial_port">/tmp/teensy_arm</param>
      <param name="baud_rate">115200</param>
    </hardware>

    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
    <joint name="base_joint">
      <command_interface name="position"/>
      <state_interface name="position"/>
      <param name="zero_us">1229</param>
      <param name="scale">0.002356</param>
      <param name="inverted">false</param>
      <param name="min_us">400</param>
      <param name="max_us">2600</param>
    </joint>

    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
    <joint name="shoulder_joint">
      <command_interface name="position"/>
      <state_interface name="position"/>
      <param name="zero_us">1673</param>
      <param name="scale">0.002356</param>
      <param name="inverted">false</param>
      <param name="min_us">995</param>
      <param name="max_us">2553</param>
    </joint>

    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
    <joint name="elbow_joint">
      <command_interface name="position"/>
      <state_interface name="position"/>
      <param name="zero_us">1320</param>
      <param name="scale">0.002356</param>
      <param name="inverted">false</param>
      <param name="min_us">680</param>
      <param name="max_us">2380</param>
    </joint>

    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
    <joint name="wrist_pitch_joint">
      <command_interface name="position"/>
      <state_interface name="position"/>
      <param name="zero_us">2230</param>
      <param name="scale">0.002356</param>
      <param name="inverted">false</param>
      <param name="min_us">1410</param>
      <param name="max_us">2600</param>
    </joint>

    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
    <joint name="gripper_joint">
      <command_interface name="position"/>
      <state_interface name="position"/>
      <param name="zero_us">1400</param>
      <param name="scale">0.002356</param>
      <param name="inverted">false</param>
      <param name="min_us">1400</param>
      <param name="max_us">1755</param>
    </joint>
  </ros2_control>

</robot>

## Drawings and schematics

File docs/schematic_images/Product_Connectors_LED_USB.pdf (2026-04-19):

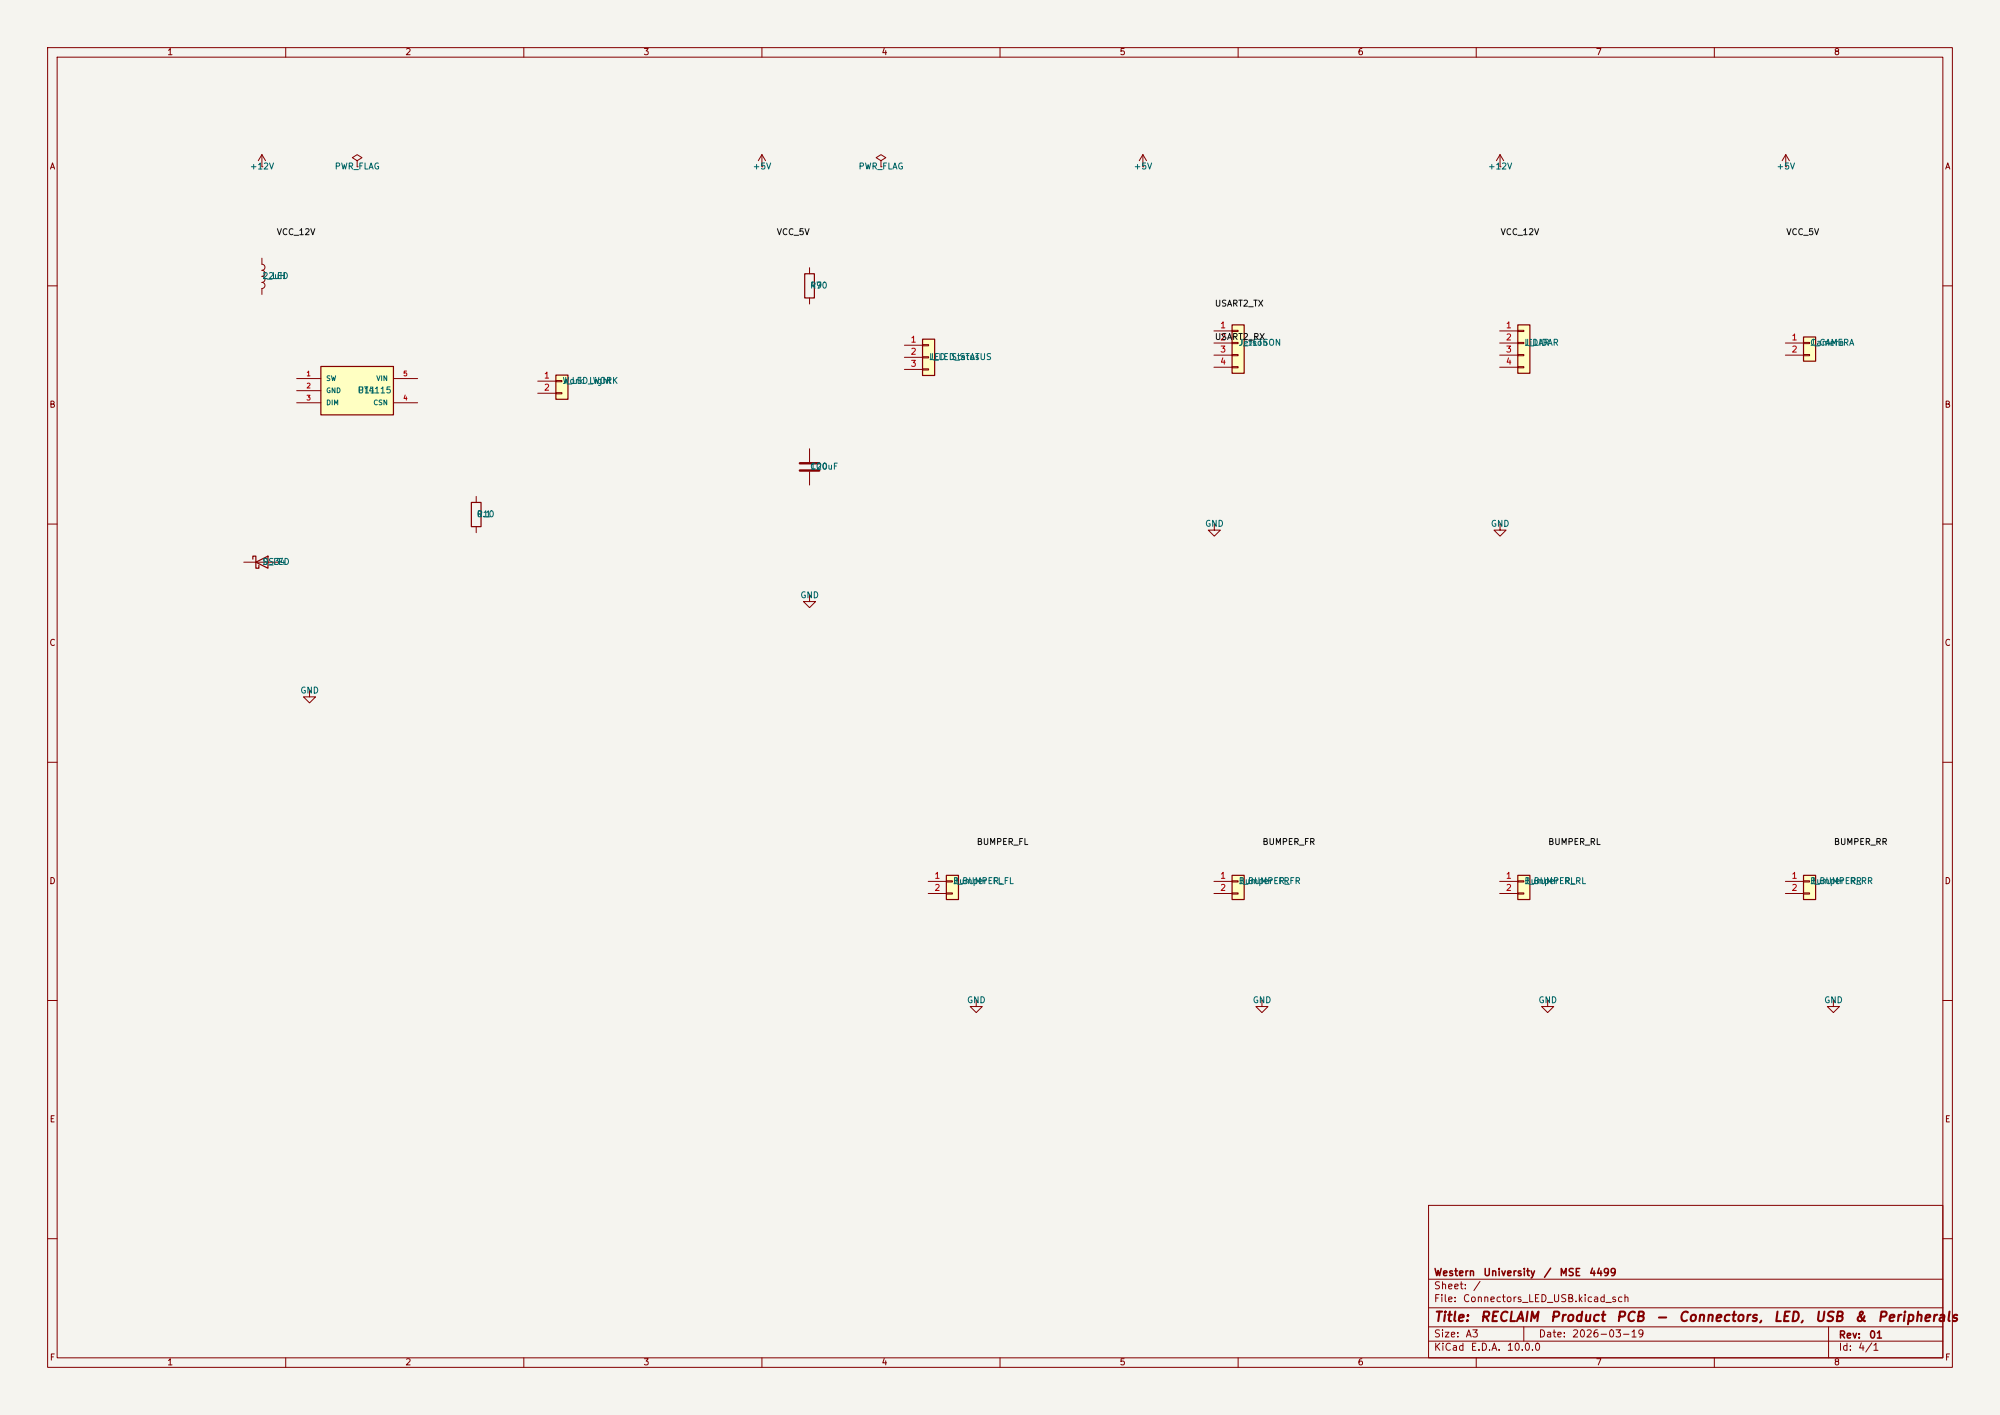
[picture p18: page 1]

Western University / MSE 4499
Sheet: /
File: Connectors_LED_USB.kicad_sch
Title: RECLAIM Product PCB - Connectors, LED, USB & Peripherals

Size: A3 | Rev: 01 | F Date: 2026-03-19 KiCad E.D.A. 10.0.0

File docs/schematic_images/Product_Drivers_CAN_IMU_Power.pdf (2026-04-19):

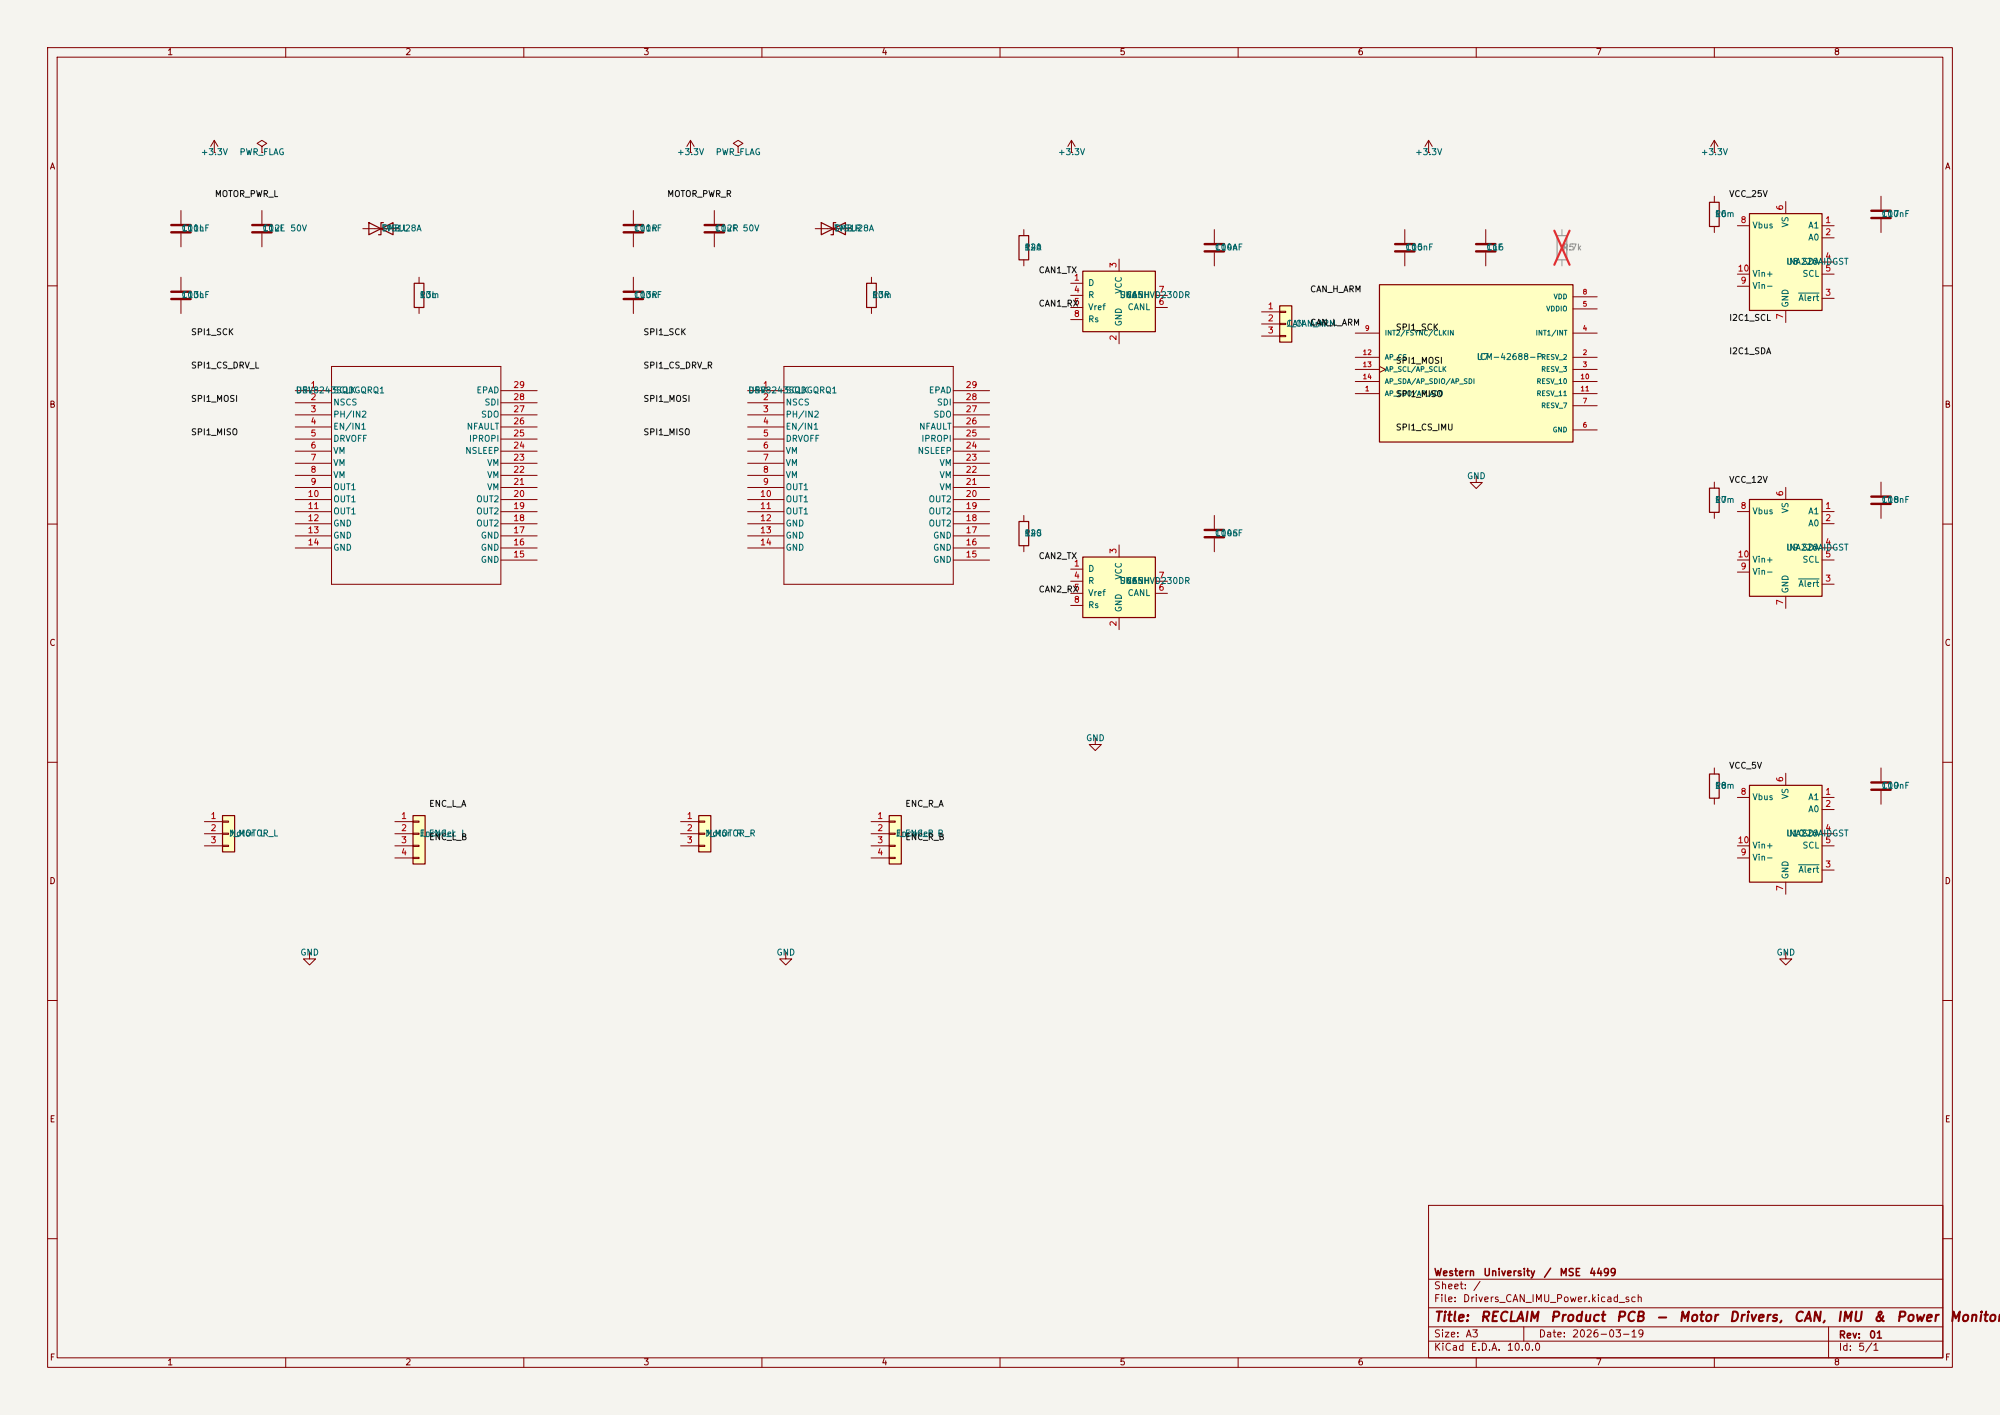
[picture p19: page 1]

Size: A3 | Rev: 01 | F Date: 2026-03-19 KiCad E.D.A. 10.0.0

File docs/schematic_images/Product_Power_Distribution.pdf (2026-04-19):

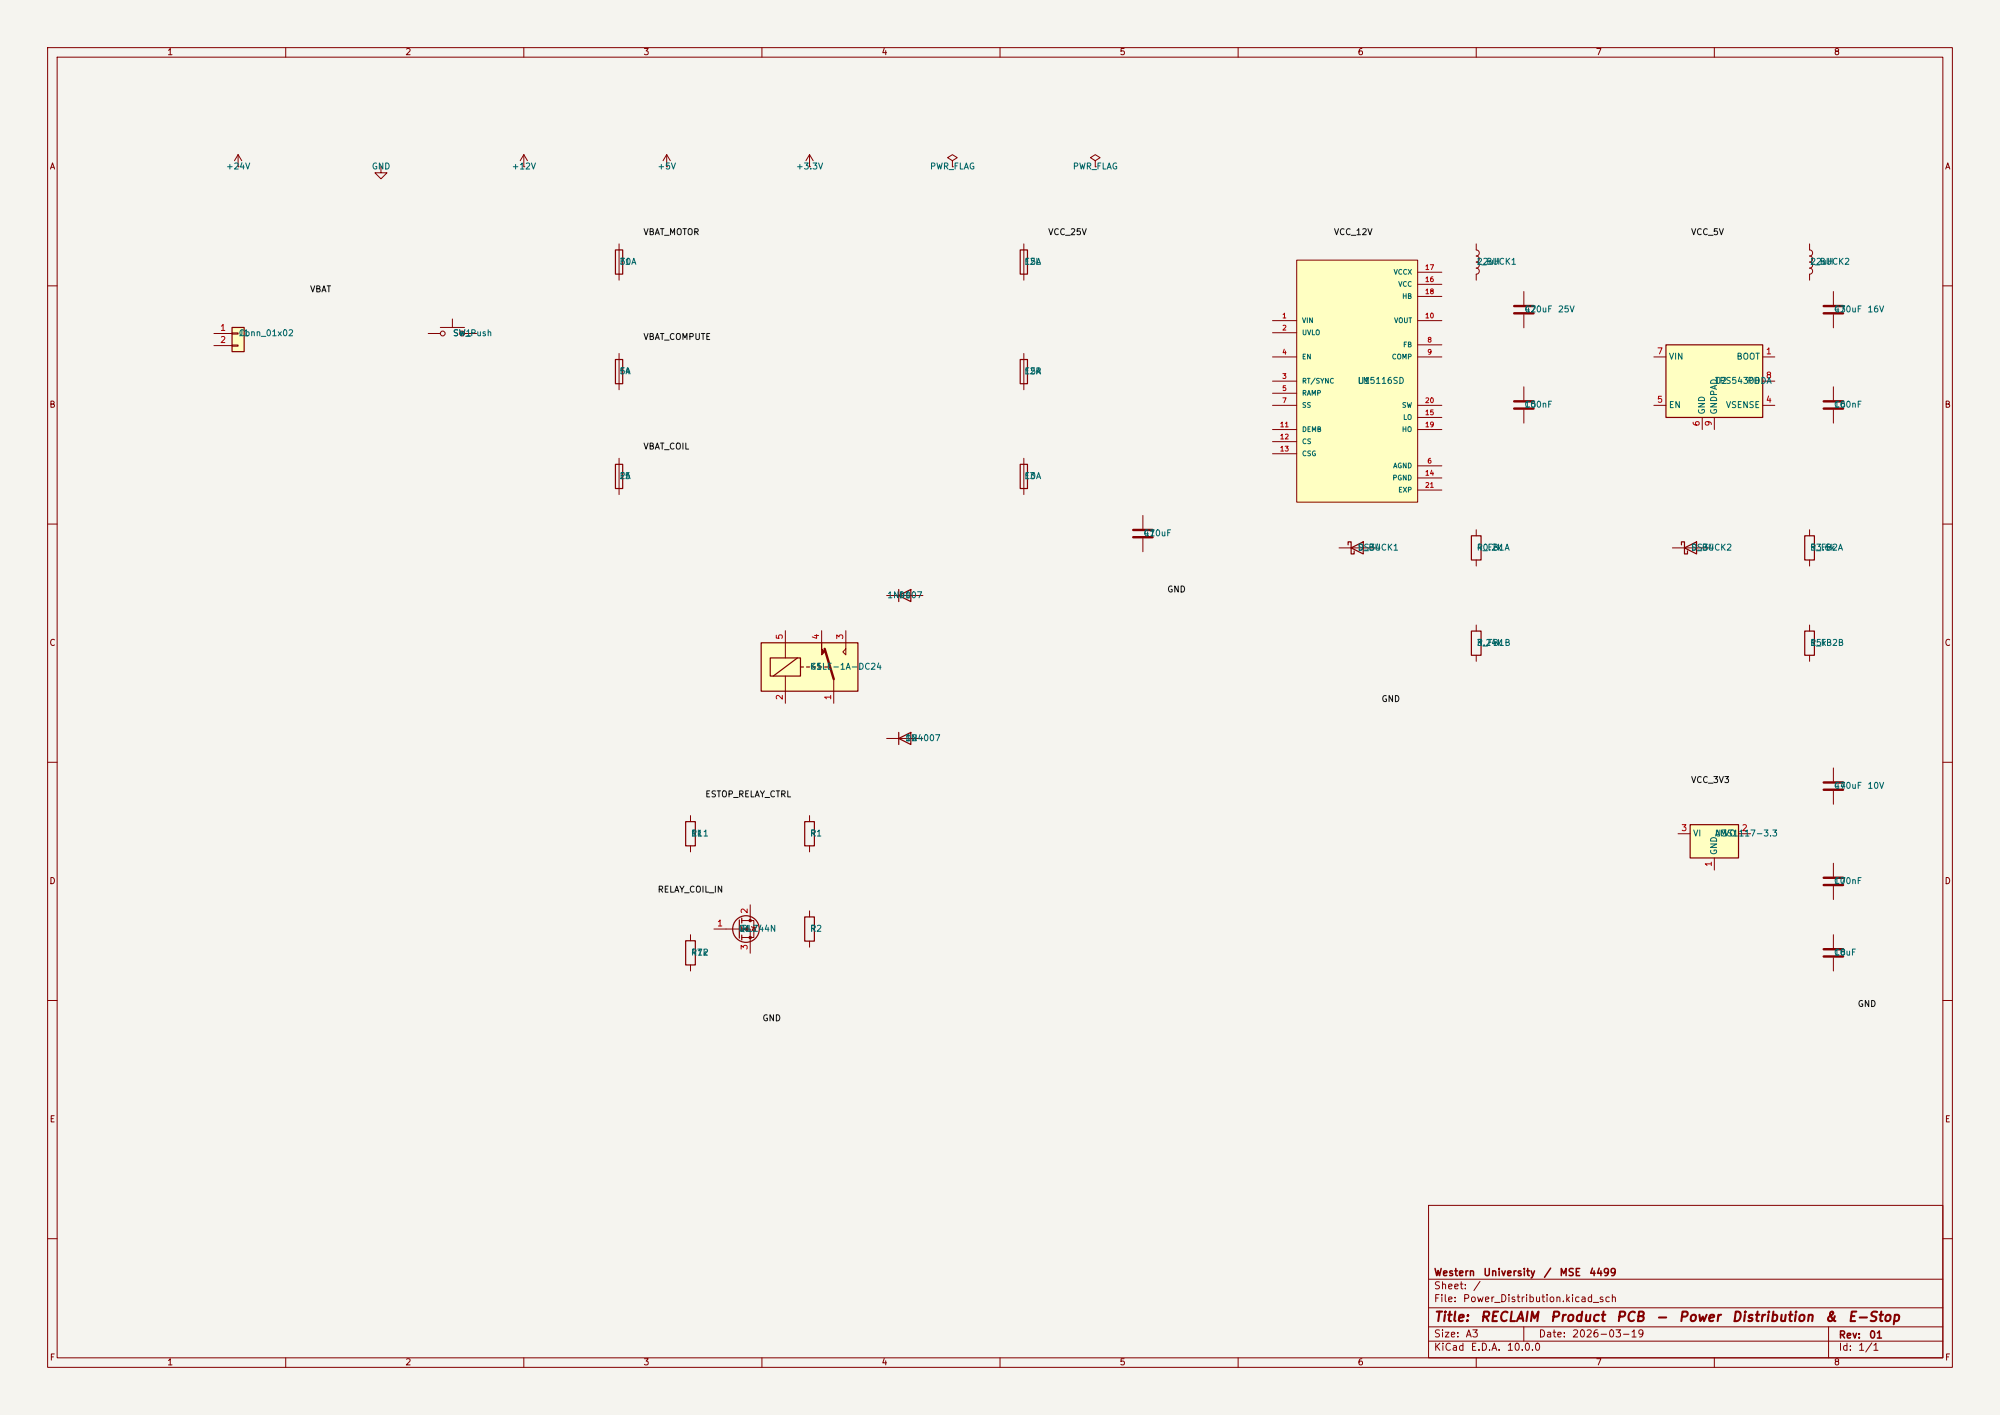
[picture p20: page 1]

Western University / MSE 4499
Sheet: /
File: Power_Distribution.kicad_sch
Title: RECLAIM Product PCB - Power Distribution & E-Stop

Size: A3 | Rev: 01 | F Date: 2026-03-19 KiCad E.D.A. 10.0.0

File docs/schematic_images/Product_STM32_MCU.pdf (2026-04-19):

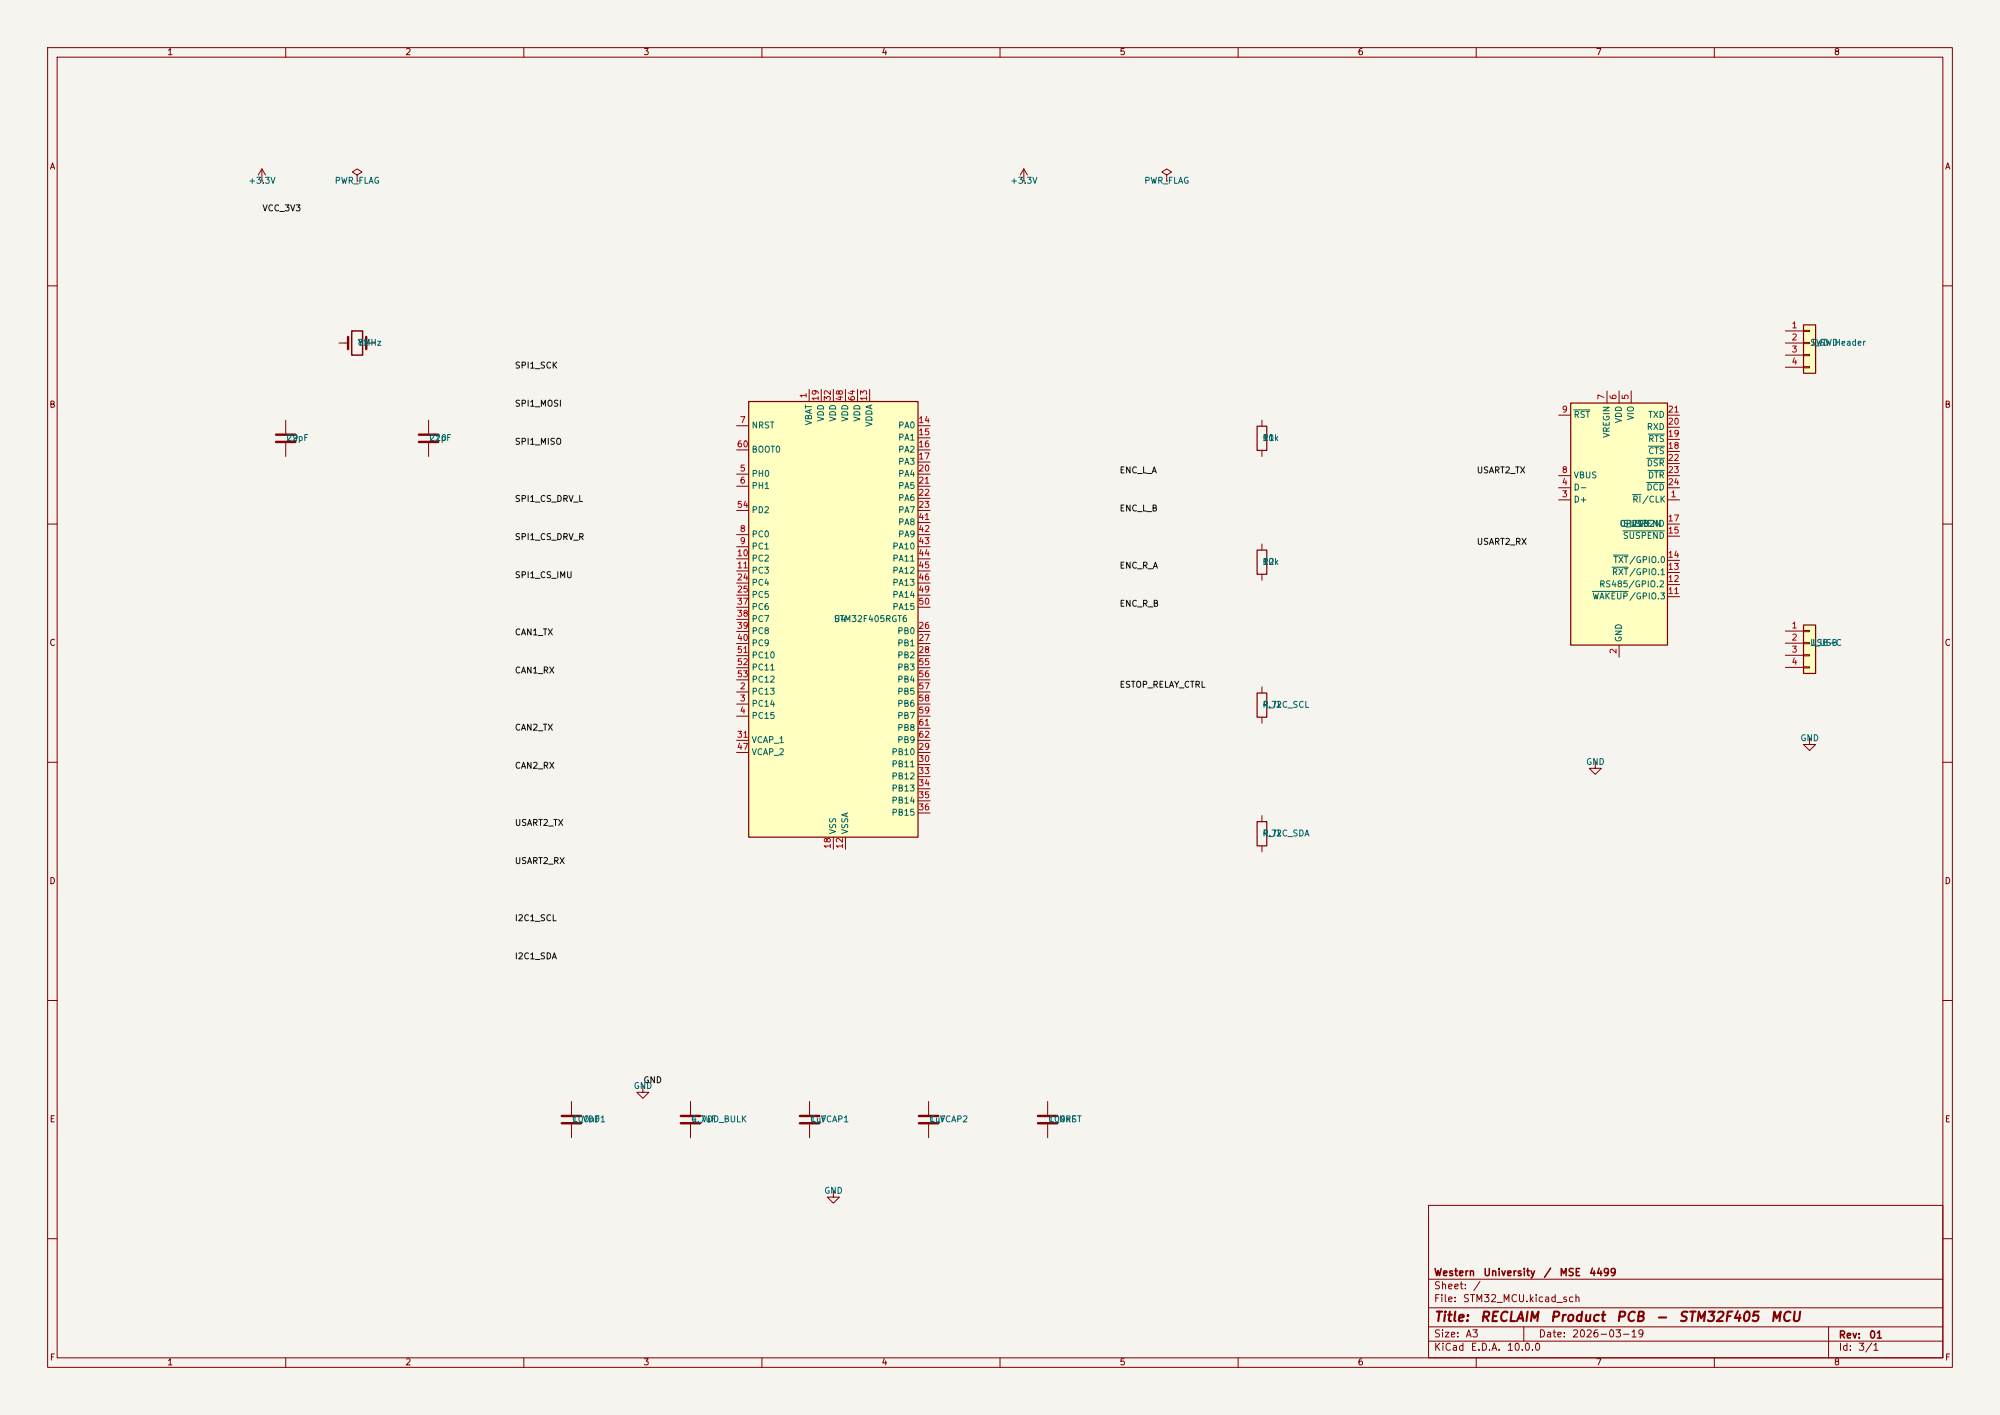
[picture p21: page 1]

Western University / MSE 4499
Sheet: /
File: STM32_MCU.kicad_sch
Title: RECLAIM Product PCB - STM32F405 MCU

Size: A3 | Rev: 01 | F Date: 2026-03-19 KiCad E.D.A. 10.0.0

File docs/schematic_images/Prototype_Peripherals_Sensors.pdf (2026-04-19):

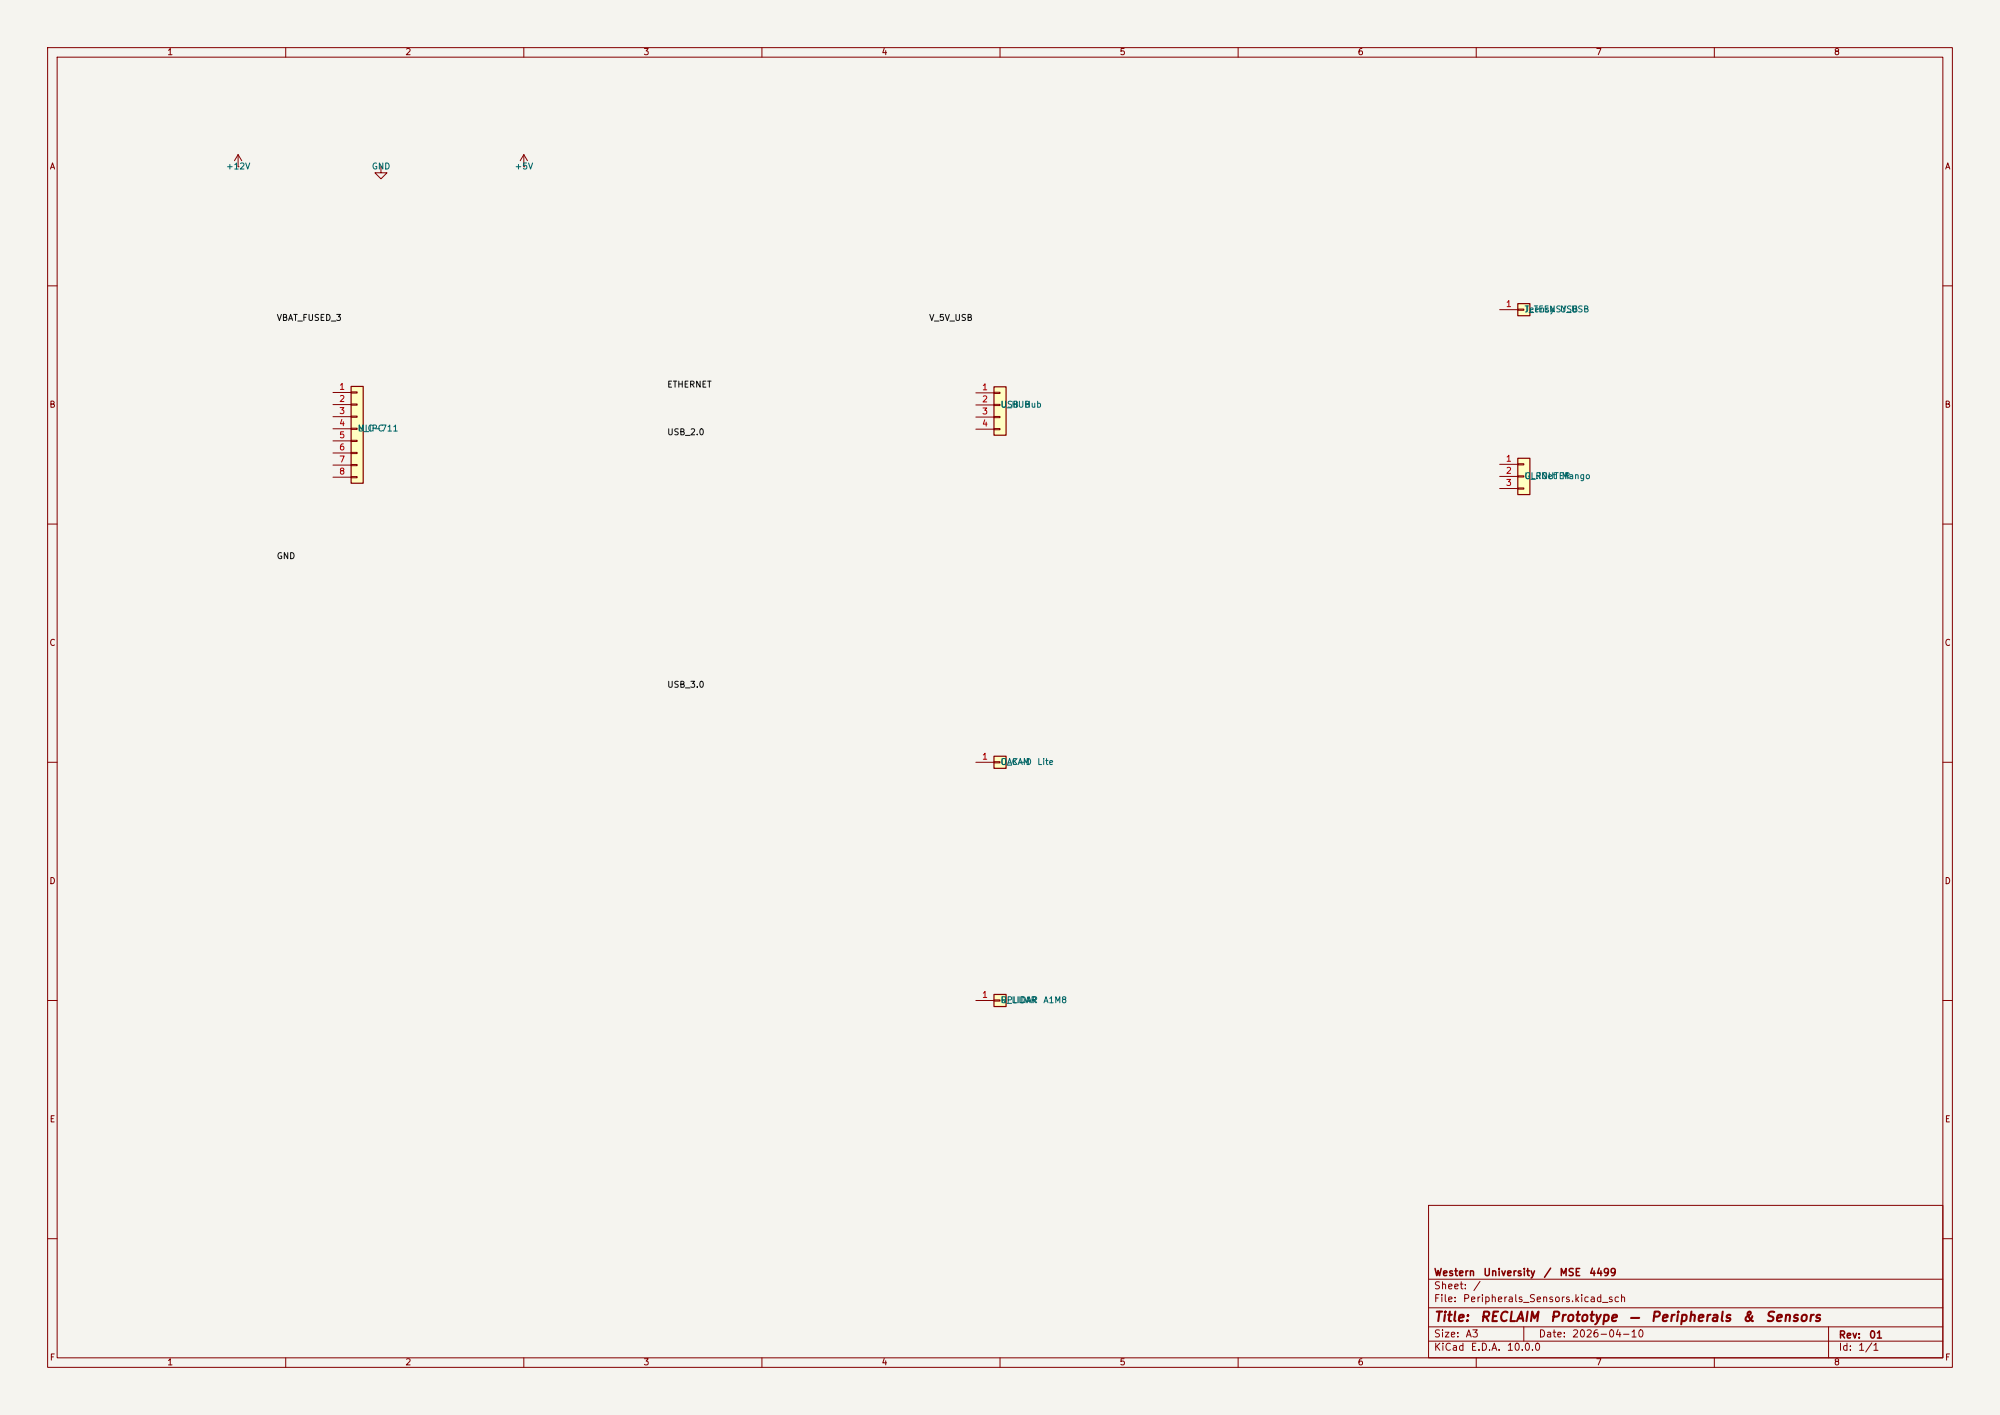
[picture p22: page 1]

Western University / MSE 4499
Sheet: /
File: Peripherals_Sensors.kicad_sch
Title: RECLAIM Prototype — Peripherals & Sensors

Size: A3 | Rev: 01 | F Date: 2026-04-10 KiCad E.D.A. 10.0.0

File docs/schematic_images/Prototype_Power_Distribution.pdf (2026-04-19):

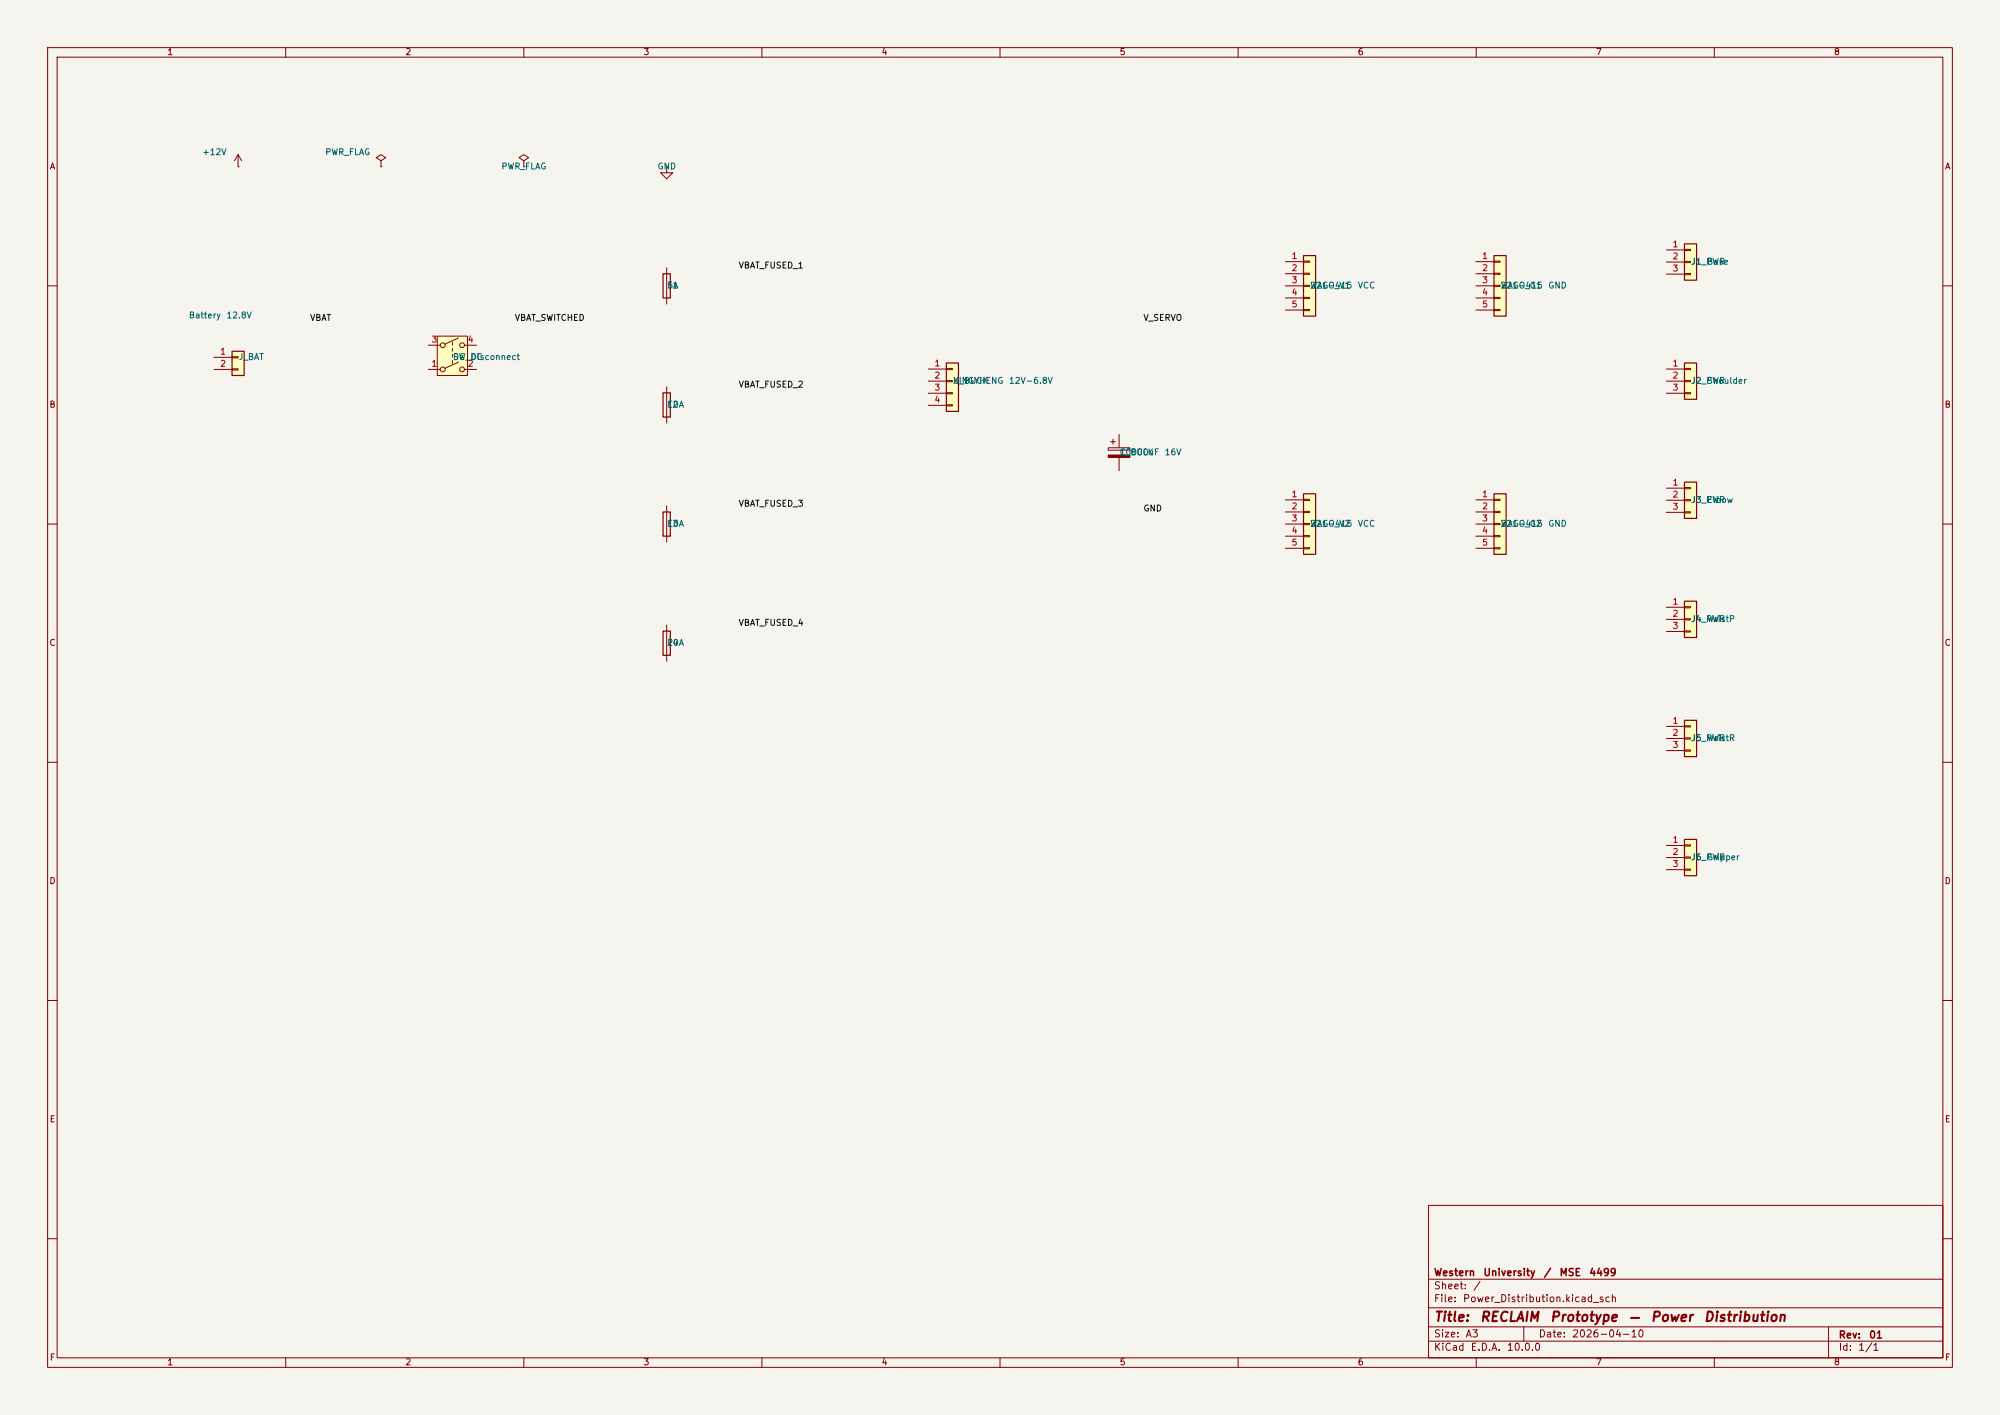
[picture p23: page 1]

Western University / MSE 4499
Sheet: /
File: Power_Distribution.kicad_sch
Title: RECLAIM Prototype — Power Distribution

Size: A3 | Rev: 01 | F Date: 2026-04-10 KiCad E.D.A. 10.0.0

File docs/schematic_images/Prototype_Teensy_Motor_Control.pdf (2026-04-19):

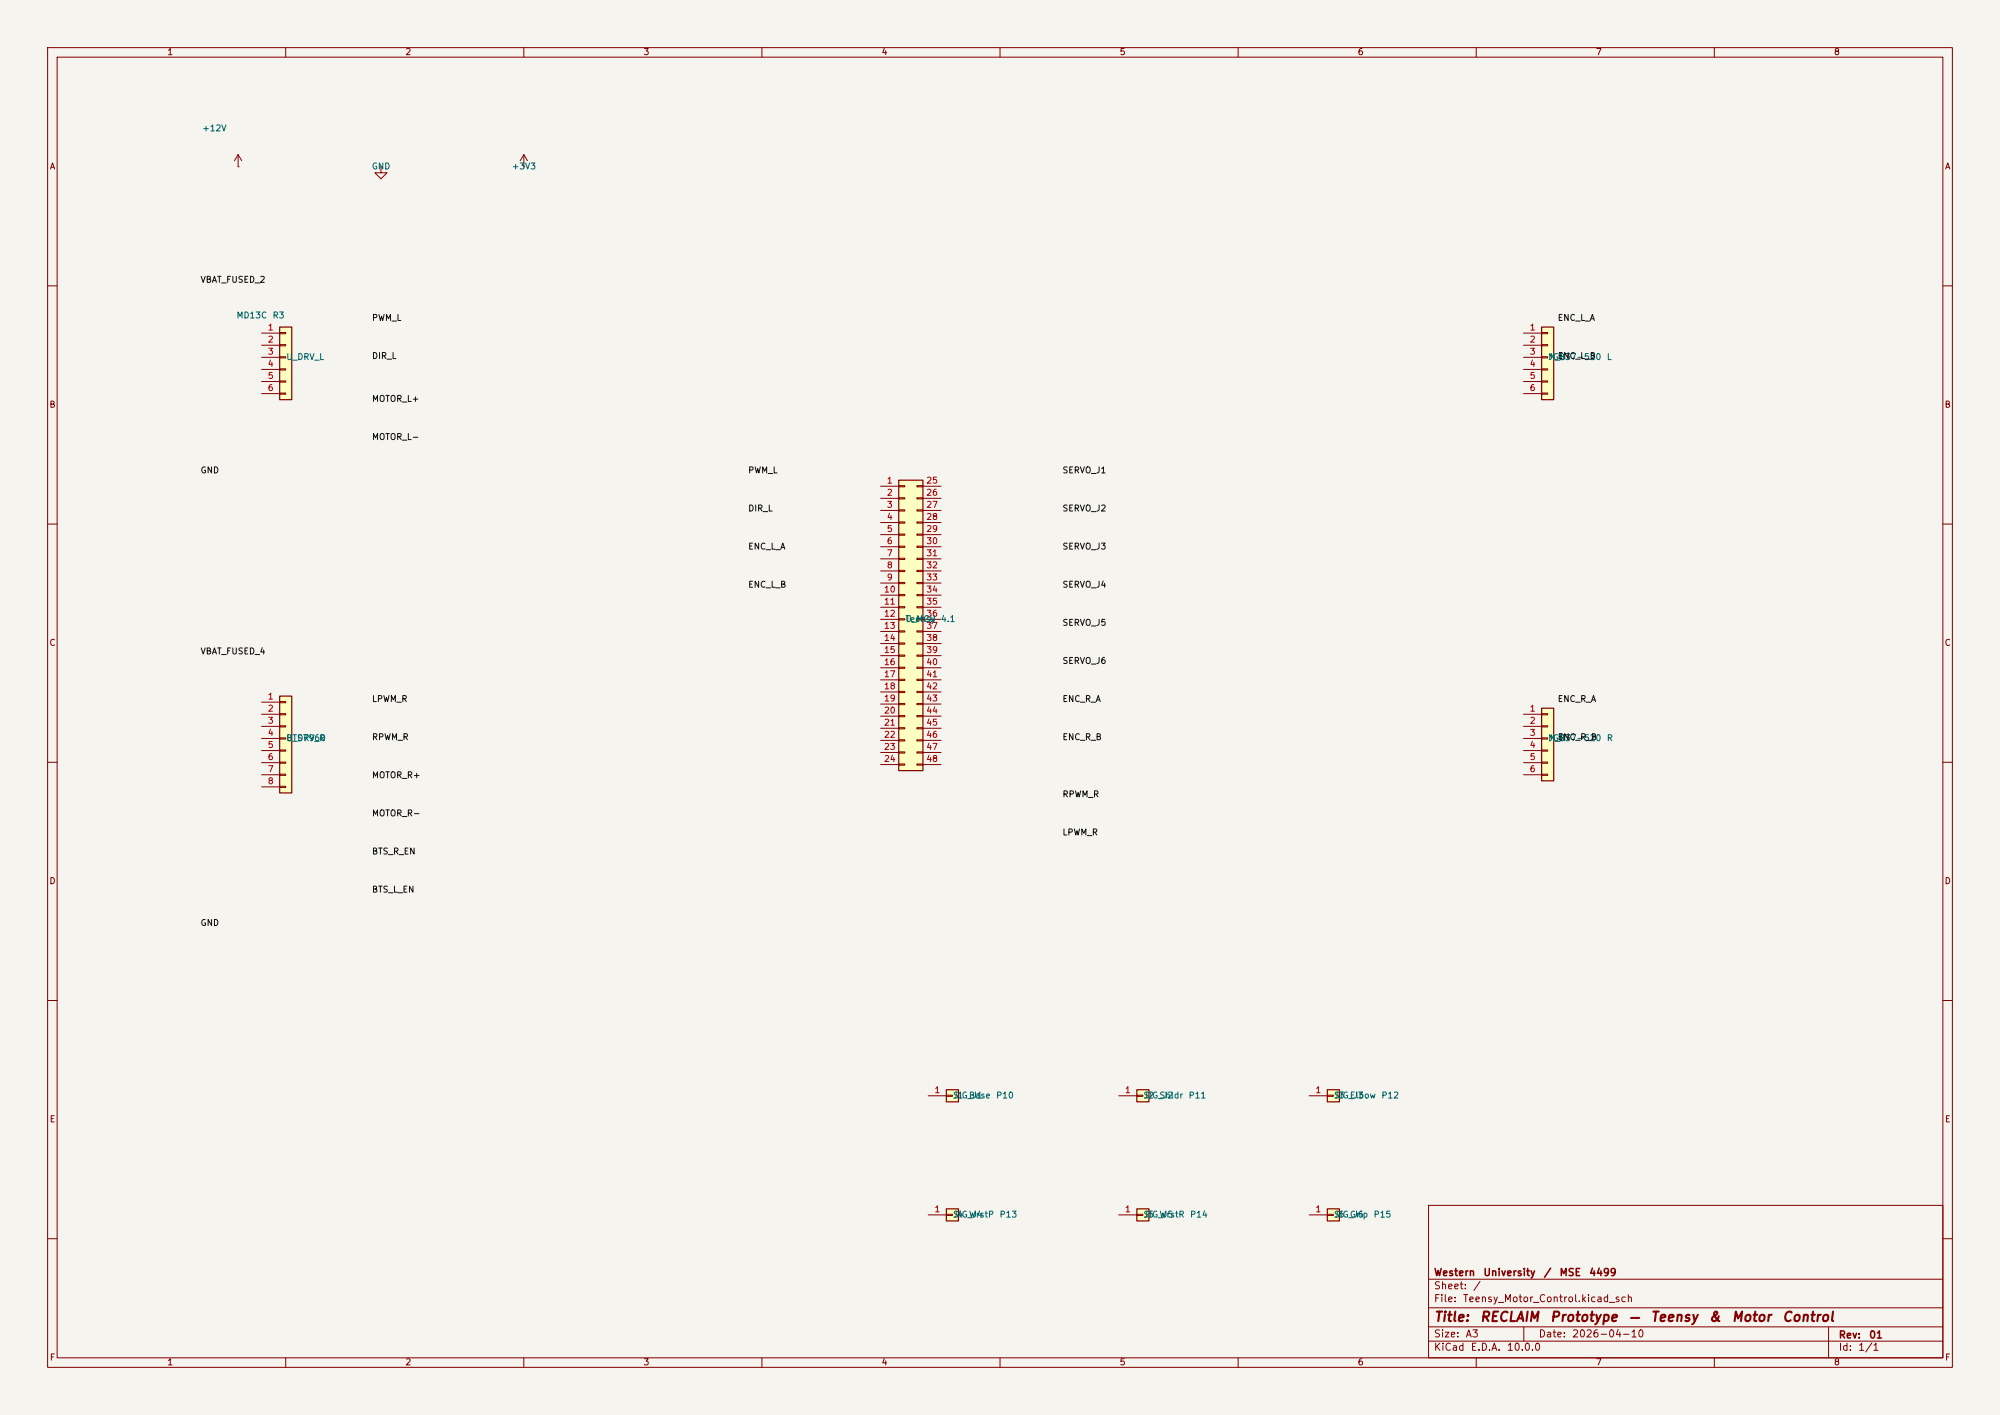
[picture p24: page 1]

Western University / MSE 4499
Sheet: /
File: Teensy_Motor_Control.kicad_sch
Title: RECLAIM Prototype — Teensy & Motor Control

Size: A3 | Rev: 01 | F Date: 2026-04-10 KiCad E.D.A. 10.0.0

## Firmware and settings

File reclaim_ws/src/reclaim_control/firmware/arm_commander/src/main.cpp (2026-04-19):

// =====================================================
// TEENSY ARM CONTROLLER — RECLAIM
// -----------------------------------------------------
// Teensy 4.1 firmware for 6-DOF servo arm control.
// Serial command interface with ARM/DISARM safety.
//
// Features
//   - 6 DOF hobby-servo arm control
//   - Serial command interface (case-insensitive)
//   - Quintic minimum-jerk interpolation at 50 Hz
//   - Named pose table stored in RAM
//   - Teach mode with NUDGE / SAVE / DELETE
//   - ARM/DISARM for safe detached startup
//   - HOLD sentinel (-999) for per-joint "keep current" in poses
//   - GRIP command for gripper-only control
//   - PICKUP command for full pick-and-sort sequence
//   - DRIVE command for differential drive motors (independent of ARM/DISARM)
//   - TICKS / RESET_TICKS for encoder feedback
//   - ESTOP for emergency stop (motors + arm)
//   - Motor safety timeout: auto-stop if no DRIVE in 500ms
//
// Serial commands
//   HELP
//   PRINT       -> print joint angles + µs
//   READUS      -> print raw µs values (for ROS2 bridge)
//   LIST
//   STOP
//   ARM         -> attach all servos at startup pose
//   DISARM      -> detach all servos (go limp)
//
//   SET j1 j2 j3 j4 j5 j6 [T ms]
//     -> joint-space degrees, use -999 for HOLD
//
//   SETUS us1 us2 us3 us4 us5 us6 [T ms]
//     -> microseconds directly, use -1 for HOLD
//     -> used by ROS2 teensy_bridge for MoveIt2 control
//
//   GOTO j1 j2 j3 j4 j5 j6
//     -> immediate write, no trajectory
//
//   POSE name
//   POSE name T ms
//
//   SAVE name
//   DELETE name
//
//   NUDGE joint_index delta_deg
//     -> example: NUDGE 1 2.0
//
//   GRIP angle [T ms]
//     -> move only gripper (J6) to angle
//
//   RUNBIN n
//     -> home -> binN_pre -> binN_drop -> binN_pre -> home
//
//   PICKUP n angle [T ms]
//     -> full pick-and-sort cycle to bin n with grip angle
//
// Notes
//   - Joint space is in degrees, J1..J6
//   - SAVE is RAM-only; saved poses are lost after reset/reflash
//   - Servos start DISARMED. Send ARM after positioning arm by hand.
//   - Poses with HOLD (-999) on a joint preserve that joint's current angle
// =====================================================

#include <Arduino.h>
#include <Servo.h>
#include <math.h>
#include <string.h>

// ---------------- USER CONFIG ----------------
static const int N = 6;

// J1..J6 on Teensy pins 10..15
static const int SERVO_PINS[N] = {
  10, 11, 12, 13, 14, 15  // Updated March 18 (J6 confirmed pin 15)
};

// Wheel motor driver pins — must be driven LOW on boot
// to prevent wheels from spinning when arm firmware is loaded.
//   Left motor:  MD10C       — PWM=2, DIR=3
//   Right motor: BTS7960     — RPWM=22, LPWM=23
// BTS7960 uses two PWM pins (RPWM for forward, LPWM for reverse)
// instead of MD10C's single PWM + DIR scheme.
// Pin 20 does NOT support PWM on Teensy 4.1, so LPWM moved to pin 23.
// BTS7960 R_EN and L_EN must be tied to 3.3V (always enabled).
static const int MOTOR_PINS[] = {2, 3, 22, 23};  // All motor control pins
static const int NUM_MOTOR_PINS = 4;

// Right motor driver type flag
static const bool RIGHT_IS_BTS7960 = true;  // false = MD10C, true = BTS7960

// --- Encoder pins ---
static const int L_ENC_A = 6;
static const int L_ENC_B = 7;
static const int R_ENC_A = 19;
static const int R_ENC_B = 18;

// --- Encoder state ---
volatile long leftTicks = 0;
volatile long rightTicks = 0;

// --- Encoder ISRs (from dual_motor_test.cpp, verified working) ---
void leftISR_A() {
  if (digitalRead(L_ENC_A) == digitalRead(L_ENC_B))
    leftTicks++;
  else
    leftTicks--;
}

void leftISR_B() {
  if (digitalRead(L_ENC_A) == digitalRead(L_ENC_B))
    leftTicks--;
  else
    leftTicks++;
}

void rightISR_A() {
  if (digitalRead(R_ENC_A) == digitalRead(R_ENC_B))
    rightTicks--;
  else
    rightTicks++;
}

void rightISR_B() {
  if (digitalRead(R_ENC_A) == digitalRead(R_ENC_B))
    rightTicks++;
  else
    rightTicks--;
}

// --- Motor drive helpers ---
static long readLeftTicks() {
  noInterrupts();
  long t = leftTicks;
  interrupts();
  return t;
}

static long readRightTicks() {
  noInterrupts();
  long t = rightTicks;
  interrupts();
  return t;
}

static void resetTicks() {
  noInterrupts();
  leftTicks = 0;
  rightTicks = 0;
  interrupts();
}

// Drive both motors. PWM is signed: -255..255. Negative = reverse.
// Direction polarity from dual_motor_test.cpp:
//   Left (MD10C):   DIR LOW  = forward, DIR HIGH = reverse
//   Right (BTS7960): RPWM = forward, LPWM = reverse
//   Right (MD10C):   DIR HIGH = forward, DIR LOW  = reverse
static void driveMotors(int leftPWM, int rightPWM) {
  // Left motor — MD10C (PWM=2, DIR=3)
  if (leftPWM >= 0) {
    digitalWrite(3, LOW);
    analogWrite(2, min(leftPWM, 255));
  } else {
    digitalWrite(3, HIGH);
    analogWrite(2, min(-leftPWM, 255));
  }

  // Right motor — pin 22 and pin 23 (BTS7960) or pin 22 and pin 20 (MD10C)
  if (RIGHT_IS_BTS7960) {
    // BTS7960: pin22=RPWM, pin23=LPWM
    if (rightPWM >= 0) {
      analogWrite(22, min(rightPWM, 255)); // RPWM forward
      analogWrite(23, 0);                  // LPWM off
    } else {
      analogWrite(22, 0);                   // RPWM off
      analogWrite(23, min(-rightPWM, 255)); // LPWM reverse
    }
  } else {
    // MD10C: PWM=22, DIR=20
    if (rightPWM >= 0) {
      digitalWrite(20, HIGH);
      analogWrite(22, min(rightPWM, 255));
    } else {
      digitalWrite(20, LOW);
      analogWrite(22, min(-rightPWM, 255));
    }
  }
}

// Motor safety timeout: stop if no DRIVE/SETVEL command in 500ms
static uint32_t lastDriveMs = 0;
static bool driveActive = false;

// ═══════════════════════════════════════════════════════════════
// PI VELOCITY CONTROLLER — per-wheel closed-loop speed control
// ═══════════════════════════════════════════════════════════════
//
// Plant model (from step response):  G(s) = K / (τs + 1)
// Controller:  u = Kf·v_target + Kp·error + Ki·∫error·dt
//
// REPLACE these constants with values from step_response.py:
//   K  = DC gain (m/s per unit PWM)
//   τ  = time constant (seconds)
//   Then compute: Kf = 1/K, and Kp/Ki from pole placement.

// --- Plant parameters (from step response test 2026-03-21, calibrated wheel_radius=0.048m) ---
// Left motor:  G(s) = 0.001073 / (0.0503s + 1)
static const float PLANT_K_L   = 0.001170f;  // DC gain: (m/s) per PWM unit (scaled from 0.001073 × 0.05232/0.048)
static const float PLANT_TAU_L = 0.0503f;    // time constant (seconds)
// Right motor: G(s) = 0.000956 / (0.0463s + 1)
static const float PLANT_K_R   = 0.001042f;  // (scaled from 0.000956 × 0.05232/0.048)
static const float PLANT_TAU_R = 0.0463f;

// --- Controller design parameters ---
static const float PI_ZETA = 0.7f;           // damping ratio (slightly underdamped)
static const float PI_WN_MULT = 1.5f;        // ωn = PI_WN_MULT / τ (reduced — increase if too sluggish)

// --- Computed PI gains (left wheel) ---
// ωn = 6/τ, Kp = (2ζωnτ - 1) / K, Ki = ωn²τ / K, Kf = 1/K
static float pi_Kp_L = (2.0f * PI_ZETA * (PI_WN_MULT / PLANT_TAU_L) * PLANT_TAU_L - 1.0f) / PLANT_K_L;
static float pi_Ki_L = ((PI_WN_MULT / PLANT_TAU_L) * (PI_WN_MULT / PLANT_TAU_L) * PLANT_TAU_L) / PLANT_K_L;
static float pi_Kf_L = 1.0f / PLANT_K_L;

// --- Computed PI gains (right wheel) ---
static float pi_Kp_R = (2.0f * PI_ZETA * (PI_WN_MULT / PLANT_TAU_R) * PLANT_TAU_R - 1.0f) / PLANT_K_R;
static float pi_Ki_R = ((PI_WN_MULT / PLANT_TAU_R) * (PI_WN_MULT / PLANT_TAU_R) * PLANT_TAU_R) / PLANT_K_R;
static float pi_Kf_R = 1.0f / PLANT_K_R;

// --- PI state ---
static float pi_integral_L = 0.0f;
static float pi_integral_R = 0.0f;
static float pi_filtered_vel_L = 0.0f;    // low-pass filtered velocity
static float pi_filtered_vel_R = 0.0f;
static float pi_target_vel_L = 0.0f;      // commanded target velocity (m/s)
static float pi_target_vel_R = 0.0f;
static float pi_ramped_vel_L = 0.0f;      // ramped target (actual setpoint for PI)
static float pi_ramped_vel_R = 0.0f;
static bool  pi_active = false;            // true when SETVEL is being used
static long  pi_prev_ticks_L = 0;
static long  pi_prev_ticks_R = 0;
static uint32_t pi_prev_time_us = 0;       // microsecond timer for precise dt

// --- PI tuning constants ---
static const float PI_DT_MS = 10.0f;       // control loop period (ms) = 100Hz
static const float PI_FILTER_ALPHA = 0.3f;  // velocity low-pass filter (0-1, lower=smoother)
static const float PI_MAX_VEL = 0.3f;       // max allowed target velocity (m/s)
static const float PI_RAMP_RATE = 0.5f;     // max acceleration (m/s²) — 0→0.1 in 200ms
static const int   PI_STATIC_FRICTION_PWM = 15;  // minimum PWM to overcome motor stiction

// --- Wheel geometry (must match teensy_bridge.yaml) ---
static const float WHEEL_RADIUS = 0.05232f;          // meters (calibrated: 0.048 × 54.5/50.0, iteration 5)
static const float TICKS_PER_REV = 7560.0f;
static const float METERS_PER_TICK = 2.0f * 3.14159265f * WHEEL_RADIUS / TICKS_PER_REV;

static void piControllerUpdate() {
  // Read current ticks (atomic)
  long ticks_L = readLeftTicks();
  long ticks_R = readRightTicks();

  // Compute dt from micros() for precision
  uint32_t now_us = micros();
  float dt = (float)(now_us - pi_prev_time_us) / 1000000.0f;
  pi_prev_time_us = now_us;

  // Guard against bad dt (first call, or overflow)
  if (dt <= 0.0f || dt > 0.1f) {
    pi_prev_ticks_L = ticks_L;
    pi_prev_ticks_R = ticks_R;
    return;
  }

  // --- Ramp rate limiter (smooth acceleration/deceleration) ---
  float max_delta = PI_RAMP_RATE * dt;  // max velocity change per tick
  if (pi_ramped_vel_L < pi_target_vel_L)
    pi_ramped_vel_L = min(pi_ramped_vel_L + max_delta, pi_target_vel_L);
  else if (pi_ramped_vel_L > pi_target_vel_L)
    pi_ramped_vel_L = max(pi_ramped_vel_L - max_delta, pi_target_vel_L);

  if (pi_ramped_vel_R < pi_target_vel_R)
    pi_ramped_vel_R = min(pi_ramped_vel_R + max_delta, pi_target_vel_R);
  else if (pi_ramped_vel_R > pi_target_vel_R)
    pi_ramped_vel_R = max(pi_ramped_vel_R - max_delta, pi_target_vel_R);

  // --- Compute measured velocity (m/s) ---
  // Encoders count negative for forward motion, so negate to get positive = forward
  float raw_vel_L = -(float)(ticks_L - pi_prev_ticks_L) * METERS_PER_TICK / dt;
  float raw_vel_R = -(float)(ticks_R - pi_prev_ticks_R) * METERS_PER_TICK / dt;
  pi_prev_ticks_L = ticks_L;
  pi_prev_ticks_R = ticks_R;

  // --- Low-pass filter (exponential moving average) ---
  pi_filtered_vel_L = PI_FILTER_ALPHA * raw_vel_L + (1.0f - PI_FILTER_ALPHA) * pi_filtered_vel_L;
  pi_filtered_vel_R = PI_FILTER_ALPHA * raw_vel_R + (1.0f - PI_FILTER_ALPHA) * pi_filtered_vel_R;

  // --- PI controller for LEFT wheel ---
  float error_L = pi_ramped_vel_L - pi_filtered_vel_L;
  float output_L = pi_Kf_L * pi_ramped_vel_L + pi_Kp_L * error_L + pi_Ki_L * pi_integral_L;

  // Anti-windup: only accumulate integral if output is not saturated
  if (output_L > -255.0f && output_L < 255.0f) {
    pi_integral_L += error_L * dt;
  }

  // Clamp output + static friction compensation (deadband kick)
  int pwm_L = (int)constrain(output_L, -255.0f, 255.0f);
  if (pwm_L > 0 && pwm_L < PI_STATIC_FRICTION_PWM) pwm_L = PI_STATIC_FRICTION_PWM;
  if (pwm_L < 0 && pwm_L > -PI_STATIC_FRICTION_PWM) pwm_L = -PI_STATIC_FRICTION_PWM;
  if (abs(pi_ramped_vel_L) < 0.001f) pwm_L = 0;  // don't kick when target is zero

  // --- PI controller for RIGHT wheel ---
  float error_R = pi_ramped_vel_R - pi_filtered_vel_R;
  float output_R = pi_Kf_R * pi_ramped_vel_R + pi_Kp_R * error_R + pi_Ki_R * pi_integral_R;

  // Anti-windup
  if (output_R > -255.0f && output_R < 255.0f) {
    pi_integral_R += error_R * dt;
  }

  // Clamp output + static friction compensation
  int pwm_R = (int)constrain(output_R, -255.0f, 255.0f);
  if (pwm_R > 0 && pwm_R < PI_STATIC_FRICTION_PWM) pwm_R = PI_STATIC_FRICTION_PWM;
  if (pwm_R < 0 && pwm_R > -PI_STATIC_FRICTION_PWM) pwm_R = -PI_STATIC_FRICTION_PWM;
  if (abs(pi_ramped_vel_R) < 0.001f) pwm_R = 0;  // don't kick when target is zero

  // --- Drive motors ---
  driveMotors(pwm_L, pwm_R);

  // Keep safety timeout alive while PI is running
  lastDriveMs = millis();
  driveActive = true;
}

static void piReset() {
  pi_integral_L = 0.0f;
  pi_integral_R = 0.0f;
  pi_filtered_vel_L = 0.0f;
  pi_filtered_vel_R = 0.0f;
  pi_ramped_vel_L = 0.0f;
  pi_ramped_vel_R = 0.0f;
  pi_target_vel_L = 0.0f;
  pi_target_vel_R = 0.0f;
  pi_prev_ticks_L = readLeftTicks();
  pi_prev_ticks_R = readRightTicks();
  pi_prev_time_us = micros();
  pi_active = false;
}

// Calibrated safe pulse limits for each servo (updated March 18)
// J1 Base:         400-2600 (DS3218, full electronic range)
// J2 Shoulder:     700-2200 (DS3218, calibrated via servo_test Mar 10)
// J3 Elbow:        400-2600 (DS3218, full electronic range)
// J4 Wrist Pitch:  500-2500 (DS3218 270°, physical limits 1400-2400µs)
// J5 Wrist Rotate: 400-2600 (MG996R, physical limits 675-2600µs)
// J6 Gripper:      1400-1755 (DS3218 + LewanSoul claw, 1400=open 1755=closed)
static int SERVO_MIN_US[N] = {
  400, 700, 400, 500, 400, 1400
};

static int SERVO_MAX_US[N] = {
  2600, 2200, 2600, 2500, 2600, 1755
};

// Safe joint limits in JOINT SPACE degrees (updated March 18)
//                  J1    J2    J3     J4      J5    J6
// J4: -13.5° = 1400µs, 121.5° = 2400µs (recalibrated March 18)
// J5: -135° to 135° (DS3218 270° replacement, recalibrated March 21)
// J6: 0° = 1400µs (open), 44° = 1755µs (closed) (new LewanSoul claw)
static float JOINT_MIN_DEG[N] = {
  -148, -135, -148, -13.5, -135,  0
};

static float JOINT_MAX_DEG[N] = {
   148,  135,  110, 121.5,  135, 44
};

// Servo angle corresponding to JOINT SPACE zero
// Fill in after defining joint zero for each joint
static float ZERO_SERVO_DEG[N] = {
  135, 135, 135, 135, 135, 0
};

// true means invert direction
static bool INVERT[N] = {
  false, false, false, false, false, false
};

// Servo travel per joint
// J1-J4 = DS3218 270°, J5 = DS3218 270° (replaced MG996R March 21), J6 = DS3218 + LewanSoul claw ~44°
static float SERVO_RANGE_DEG[N] = {
  270, 270, 270, 270, 270, 44
};

// 50 Hz update
static const uint32_t DT_MS = 20;

// Default move time
static const uint32_t DEFAULT_T_MS = 1000;

// Sentinel value: "hold current position" for any joint in a pose
static const float HOLD = -999.0f;

// Safe startup pose in JOINT SPACE (home position) — recalibrated March 21
// Verified µs: J1=1229, J2=2153, J3=2030, J4=1400, J5=701, J6=1500
static float STARTUP_Q[N] = {
  -33, 127, 65, -13.5, -98.0, 12.5
};

// Max runtime poses in RAM
static const int MAX_POSES = 20;
static const int MAX_NAME_LEN = 20;

// ---------------- INTERNAL STATE ----------------
Servo servos[N];
bool armed = false;

float q_cur[N] = {0, 0, 0, 0, 0, 0};
float q0[N], qf[N];

uint32_t t_start_ms = 0;
uint32_t T_ms = 0;
bool traj_active = false;
bool abort_all = false;

String rxLine;
uint32_t last_update_ms = 0;

// ---------------- POSE TABLE ----------------
struct PoseEntry {
  bool used;
  char name[MAX_NAME_LEN];
  float q[N];
};

PoseEntry poseTable[MAX_POSES];

// ---------------- FORWARD DECLARATIONS ----------------
static void handleLine(String s);
static void serviceSerial();

// ---------------- HELPERS ----------------
static float clampf(float v, float lo, float hi) {
  if (v < lo) return lo;
  if (v > hi) return hi;
  return v;
}

static void copyQ(float dst[N], const float src[N]) {
  for (int i = 0; i < N; i++) dst[i] = src[i];
}

static bool streq_nocase(const char* a, const char* b) {
  while (*a && *b) {
    char ca = *a;
    char cb = *b;
    if (ca >= 'A' && ca <= 'Z') ca = ca - 'A' + 'a';
    if (cb >= 'A' && cb <= 'Z') cb = cb - 'A' + 'a';
    if (ca != cb) return false;
    ++a;
    ++b;
  }
  return (*a == '\0' && *b == '\0');
}

static bool startsWithIgnoreCase(const String& s, const char* prefix) {
  int n = strlen(prefix);
  if ((int)s.length() < n) return false;
  for (int i = 0; i < n; i++) {
    char a = s[i];
    char b = prefix[i];
    if (a >= 'A' && a <= 'Z') a = a - 'A' + 'a';
    if (b >= 'A' && b <= 'Z') b = b - 'A' + 'a';
    if (a != b) return false;
  }
  return true;
}

// Quintic scaling function
// s(tau) = 10 tau^3 - 15 tau^4 + 6 tau^5
static float s_quintic(float tau) {
  float t2 = tau * tau;
  float t3 = t2 * tau;
  float t4 = t3 * tau;
  float t5 = t4 * tau;
  return 10.0f * t3 - 15.0f * t4 + 6.0f * t5;
}

// Joint-space degrees -> servo pulse width
static int jointDegToUs(int i, float jointDeg) {
  // Clamp joint-space
  jointDeg = clampf(jointDeg, JOINT_MIN_DEG[i], JOINT_MAX_DEG[i]);

  // Map joint-space to servo-angle
  float sign = INVERT[i] ? -1.0f : 1.0f;
  float servoDeg = ZERO_SERVO_DEG[i] + sign * jointDeg;

  // Clamp servo angle to servo travel
  servoDeg = clampf(servoDeg, 0.0f, SERVO_RANGE_DEG[i]);

  // Linear map servo angle to pulse width
  float us = SERVO_MIN_US[i]
           + (servoDeg / SERVO_RANGE_DEG[i]) * (SERVO_MAX_US[i] - SERVO_MIN_US[i]);

  int us_i = (int)lroundf(us);

  if (us_i < SERVO_MIN_US[i]) us_i = SERVO_MIN_US[i];
  if (us_i > SERVO_MAX_US[i]) us_i = SERVO_MAX_US[i];

  return us_i;
}

static void writeAll() {
  if (!armed) return;
  for (int i = 0; i < N; i++) {
    servos[i].writeMicroseconds(jointDegToUs(i, q_cur[i]));
  }
}

static void printCompactQ() {
  Serial.print("Q: ");
  for (int i = 0; i < N; i++) {
    Serial.print(q_cur[i], 2);
    if (i < N - 1) Serial.print(" ");
  }
  Serial.println();
}

static void printQ() {
  Serial.println("STATE:");
  for (int i = 0; i < N; i++) {
    Serial.print("  J");
    Serial.print(i + 1);
    Serial.print(": q=");
    Serial.print(q_cur[i], 2);
    Serial.print(" deg, us=");
    Serial.println(jointDegToUs(i, q_cur[i]));
  }
  Serial.print("  Armed: ");
  Serial.println(armed ? "YES" : "NO");
}

// ---------------- POSE TABLE FUNCTIONS ----------------
static int findPoseIndex(const char* name) {
  for (int i = 0; i < MAX_POSES; i++) {
    if (poseTable[i].used && streq_nocase(poseTable[i].name, name)) {
      return i;
    }
  }
  return -1;
}

static int findFreePoseSlot() {
  for (int i = 0; i < MAX_POSES; i++) {
    if (!poseTable[i].used) return i;
  }
  return -1;
}

static bool getPoseByName(const char* name, float out[N]) {
  int idx = findPoseIndex(name);
  if (idx < 0) return false;
  copyQ(out, poseTable[idx].q);
  return true;
}

static bool savePoseByName(const char* name, const float q[N]) {
  if (strlen(name) == 0 || strlen(name) >= MAX_NAME_LEN) return false;

  int idx = findPoseIndex(name);
  if (idx < 0) idx = findFreePoseSlot();
  if (idx < 0) return false;

  poseTable[idx].used = true;
  strncpy(poseTable[idx].name, name, MAX_NAME_LEN - 1);
  poseTable[idx].name[MAX_NAME_LEN - 1] = '\0';
  copyQ(poseTable[idx].q, q);

  return true;
}

static bool deletePoseByName(const char* name) {
  int idx = findPoseIndex(name);
  if (idx < 0) return false;

  poseTable[idx].used = false;
  poseTable[idx].name[0] = '\0';
  for (int j = 0; j < N; j++) poseTable[idx].q[j] = 0.0f;

  return true;
}

static void listPoses() {
  Serial.println("POSES:");
  bool any = false;
  for (int i = 0; i < MAX_POSES; i++) {
    if (poseTable[i].used) {
      any = true;
      Serial.print("  ");
      Serial.print(poseTable[i].name);
      Serial.print(" = ");
      for (int j = 0; j < N; j++) {
        if (poseTable[i].q[j] <= HOLD + 0.5f) {
          Serial.print("HOLD");
        } else {
          Serial.print(poseTable[i].q[j], 1);
        }
        if (j < N - 1) Serial.print(" ");
      }
      Serial.println();
    }
  }
  if (!any) Serial.println("  (none)");
}

static void initPoseTable() {
  for (int i = 0; i < MAX_POSES; i++) {
    poseTable[i].used = false;
    poseTable[i].name[0] = '\0';
    for (int j = 0; j < N; j++) poseTable[i].q[j] = 0.0f;
  }

  // Hardcoded taught poses — recalibrated March 18
  // HOLD = -999 means "keep current joint position"
  // NOTE: Only HOME is verified. Other poses need re-teaching after J4/J5/J6 hardware changes.
  static const float HOME[N]           = { -33, 127,  65, -13.5, -98.0,  12.5};  // verified March 21 (µs: 1229,2153,2030,1400,701,1500)
  static const float HOME_CARRY[N]     = { -33, 127,  65, -13.5, -98.0, HOLD};   // transport (keeps grip)
  static const float PREPICK[N]        = { -33,  75,  65,  20,   21,    0};    // NEEDS RE-TEACHING
  static const float PREPICK_CARRY[N]  = { -33,  75,  65,  20,   21, HOLD};   // NEEDS RE-TEACHING
  static const float PICKUP_POSE[N]    = { -33,  65,  65,  20,   21,   35};   // NEEDS RE-TEACHING

  savePoseByName("home",           HOME);
  savePoseByName("home_carry",     HOME_CARRY);
  savePoseByName("prepick",        PREPICK);
  savePoseByName("prepick_carry",  PREPICK_CARRY);
  savePoseByName("pickup",         PICKUP_POSE);
}

// ---------------- TRAJECTORY ----------------
static void startTraj(const float target[N], uint32_t duration_ms) {
  abort_all = false;

  for (int i = 0; i < N; i++) {
    q0[i] = q_cur[i];
    if (target[i] <= HOLD + 0.5f) {
      qf[i] = q_cur[i];  // HOLD: keep current position
    } else {
      qf[i] = clampf(target[i], JOINT_MIN_DEG[i], JOINT_MAX_DEG[i]);
    }
  }

  T_ms = (duration_ms < 100) ? 100 : duration_ms;
  t_start_ms = millis();
  traj_active = true;

  Serial.print("OK T=");
  Serial.println(T_ms);
}
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
void loop() {
  serviceSerial();

  uint32_t now = millis();

  // Servo trajectory update at 50Hz (20ms)
  if (now - last_update_ms >= DT_MS) {
    last_update_ms = now;
    updateTraj();
  }

  // PI velocity controller update at 100Hz (10ms)
  if (pi_active && (now - lastPiMs >= (uint32_t)PI_DT_MS)) {
    lastPiMs = now;
    piControllerUpdate();
  }

  // Motor safety timeout: stop wheels if no DRIVE/SETVEL command in 500ms
  if (driveActive && (now - lastDriveMs > 500)) {
    driveMotors(0, 0);
    driveActive = false;
    if (pi_active) piReset();
  }
}

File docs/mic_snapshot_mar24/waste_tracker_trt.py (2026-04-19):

#!/usr/bin/env python3
"""
waste_tracker_trt.py — TRT API version of the waste tracker.

Same autonomous state machine as waste_tracker.py, but polls the TRT detection
server's HTTP API at localhost:8081/detection instead of running its own camera.

The TRT server (Python 3.8 + TensorRT) runs camera + YOLO at 30 FPS.
This node handles DRIVING ONLY (SCAN → TURN → APPROACH → ALIGN).
Arm pickup is handled by pick_and_place.py via /pickup_request topic.

Data flow:
  TRT server (30 FPS) → HTTP /detection → this node → /cmd_vel → motors
  After ALIGN: publishes /pickup_request → pick_and_place.py handles arm

Usage:
  ros2 run reclaim_bringup waste_tracker_trt --ros-args \
      -p trt_url:=http://localhost:8081 \
      -p drive_only:=true

Authors: Shady Siam, Issa Ahmed
"""

from __future__ import annotations

import json
import math
import threading
import time
import urllib.request
from dataclasses import dataclass
from enum import Enum, auto
from typing import List, Optional, Tuple

import numpy as np

try:
    import cv2
    HAS_CV2 = True
except ImportError:
    HAS_CV2 = False

import rclpy
from rclpy.node import Node
from geometry_msgs.msg import Twist
from nav_msgs.msg import Odometry
from std_msgs.msg import String


# ══════════════════════════════════════════════════════════════════════
#  Constants
# ══════════════════════════════════════════════════════════════════════

CLASS_NAMES = {
    0: 'plastic_bottle', 1: 'aluminum_can', 2: 'cardboard',
    3: 'plastic_container', 4: 'cup', 5: 'chip_bag',
    6: 'styrofoam_container', 7: 'napkin', 8: 'paper_bag',
    9: 'apple', 10: 'orange',
}

BIN_MAP = {
    'plastic_bottle': 'recyclable', 'aluminum_can': 'recyclable',
    'cardboard': 'recyclable', 'plastic_container': 'recyclable',
    'cup': 'landfill', 'chip_bag': 'landfill',
    'styrofoam_container': 'landfill', 'napkin': 'compost',
    'paper_bag': 'compost', 'apple': 'compost', 'orange': 'compost',
}


class State(Enum):
    IDLE = auto()
    SCAN = auto()
    TURN_TO_TARGET = auto()
    APPROACH = auto()
    ALIGN = auto()
    PICK = auto()


@dataclass
class Detection:
    """A single detected waste item with 3D position."""
    class_name: str
    confidence: float
    cam_x: float
    cam_y: float
    cam_z: float
    robot_x: float
    robot_y: float
    robot_z: float
    cx_px: int
    cy_px: int
    bbox_w: float
    bbox_h: float

    @property
    def distance_mm(self) -> float:
        return math.sqrt(self.robot_x ** 2 + self.robot_y ** 2)

    @property
    def bearing_rad(self) -> float:
        return math.atan2(self.robot_y, self.robot_x)


# ══════════════════════════════════════════════════════════════════════
#  WasteTracker ROS2 Node
# ══════════════════════════════════════════════════════════════════════

class WasteTracker(Node):
    def __init__(self):
        super().__init__('waste_tracker')

        # ── ROS Parameters ────────────────────────────────────────────
        self.declare_parameter('trt_url', 'http://localhost:8081')
        self.declare_parameter('confidence', 0.50)
        self.declare_parameter('poll_rate_hz', 20.0)

        # SCAN parameters
        self.declare_parameter('scan_angular_vel', 0.3)
        self.declare_parameter('scan_full_rotation', 6.28)

        # APPROACH parameters
        self.declare_parameter('approach_linear_vel', 0.25)
        self.declare_parameter('approach_angular_gain', 0.003)
        self.declare_parameter('approach_linear_gain', 0.0003)
        self.declare_parameter('approach_stop_distance_mm', 250.0)  # cam_z fallback
        self.declare_parameter('approach_stop_base_x_mm', 200.0)  # base_x from J1 (primary)

        # ALIGN parameters
        self.declare_parameter('align_pixel_tolerance', 30)
        self.declare_parameter('align_angular_vel', 0.15)
        self.declare_parameter('align_stable_frames', 5)
        self.declare_parameter('align_min_depth_mm', 150.0)
        self.declare_parameter('align_max_depth_mm', 450.0)

        # Obstacle avoidance
        self.declare_parameter('obstacle_min_depth_mm', 300.0)
        self.declare_parameter('drive_only', True)  # Default: driving only, arm handled separately

        # ── Read parameters ───────────────────────────────────────────
        self.trt_url = self.get_parameter('trt_url').value.rstrip('/')
        self.confidence = self.get_parameter('confidence').value
        self.poll_rate_hz = self.get_parameter('poll_rate_hz').value
        self.last_trt_timestamp = 0.0

        self.scan_vel = self.get_parameter('scan_angular_vel').value
        self.scan_target = self.get_parameter('scan_full_rotation').value

        self.approach_max_v = self.get_parameter('approach_linear_vel').value
        self.approach_w_gain = self.get_parameter('approach_angular_gain').value
        self.approach_v_gain = self.get_parameter('approach_linear_gain').value
        self.approach_stop_dist = self.get_parameter('approach_stop_distance_mm').value
        self.approach_stop_base_x = self.get_parameter('approach_stop_base_x_mm').value

        self.align_px_tol = self.get_parameter('align_pixel_tolerance').value
        self.align_w = self.get_parameter('align_angular_vel').value
        self.align_stable_needed = self.get_parameter('align_stable_frames').value
        self.align_min_depth = self.get_parameter('align_min_depth_mm').value
        self.align_max_depth = self.get_parameter('align_max_depth_mm').value

        self.obstacle_min = self.get_parameter('obstacle_min_depth_mm').value
        self.drive_only = self.get_parameter('drive_only').value

        # ── State machine ─────────────────────────────────────────────
        self.state = State.IDLE
        self.scan_start_yaw = 0.0
        self.scan_accumulated = 0.0
        self.scan_detections: List[Detection] = []
        self.current_target: Optional[Detection] = None
        self.align_stable_count = 0
        self.current_yaw = 0.0
        self.prev_yaw = None
        self.items_collected = 0
        self.drive_only_done = False
        self.filtered_angular_z = 0.0
        self.last_angular_z = 0.0
        self.target_lost_count = 0
        self.target_lost_threshold = 50

        # Detection confirmation
        self.confirm_count = 0
        self.confirm_threshold = 3
        self.confirm_candidate = None

        # Simple P control for 30 FPS (no PID/Kalman needed — data is already smooth)
        self.angular_kp = 0.003         # P gain for TURN: pixel offset → rad/s
        self.angular_kp_approach = 0.002  # softer P gain during APPROACH (less jitter)
        self.angular_min_cmd = 0.04     # minimum command to overcome motor deadband
        self.angular_alpha = 0.5        # light EMA (0.5 = half raw, half filtered)
        self.turn_center_tol = 50       # px — transition to APPROACH when within this
        self.turn_max_angular = 0.20    # rad/s max during TURN (was 0.15)
        self.approach_center_tol = 15   # px — deadband during approach
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

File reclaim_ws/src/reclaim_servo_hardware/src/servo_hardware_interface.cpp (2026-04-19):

#include "reclaim_servo_hardware/servo_hardware_interface.hpp"

#include <algorithm>
#include <cmath>
#include <cstring>
#include <limits>
#include <sstream>

// Linux serial
#include <fcntl.h>
#include <termios.h>
#include <unistd.h>

#include "pluginlib/class_list_macros.hpp"

namespace reclaim_servo_hardware
{

// ---------------------------------------------------------------
// on_init: parse URDF ros2_control parameters
// ---------------------------------------------------------------
CallbackReturn ServoHardwareInterface::on_init(
  const hardware_interface::HardwareInfo & info)
{
  if (hardware_interface::SystemInterface::on_init(info) != CallbackReturn::SUCCESS)
  {
    return CallbackReturn::ERROR;
  }

  // Hardware-level parameters
  serial_port_ = info_.hardware_parameters.at("serial_port");
  baud_rate_ = std::stoi(info_.hardware_parameters.at("baud_rate"));

  const size_t n = info_.joints.size();
  hw_commands_.resize(n, 0.0);
  hw_states_.resize(n, 0.0);
  prev_commands_.resize(n, std::numeric_limits<double>::quiet_NaN());
  calibrations_.resize(n);

  // Read per-joint calibration from URDF <param> tags
  for (size_t i = 0; i < n; i++)
  {
    const auto & joint = info_.joints[i];

    calibrations_[i].zero_us  = std::stod(joint.parameters.at("zero_us"));
    calibrations_[i].scale    = std::stod(joint.parameters.at("scale"));
    calibrations_[i].inverted = (joint.parameters.at("inverted") == "true");
    calibrations_[i].min_us   = std::stod(joint.parameters.at("min_us"));
    calibrations_[i].max_us   = std::stod(joint.parameters.at("max_us"));

    RCLCPP_INFO(rclcpp::get_logger("ServoHardwareInterface"),
      "Joint[%zu] '%s': zero=%.0f scale=%.6f inv=%s range=[%.0f, %.0f]",
      i, joint.name.c_str(),
      calibrations_[i].zero_us, calibrations_[i].scale,
      calibrations_[i].inverted ? "true" : "false",
      calibrations_[i].min_us, calibrations_[i].max_us);
  }

  RCLCPP_INFO(rclcpp::get_logger("ServoHardwareInterface"),
    "Initialized %zu joints. Serial: %s @ %d baud",
    n, serial_port_.c_str(), baud_rate_);

  return CallbackReturn::SUCCESS;
}
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

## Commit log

2026-04-10 Fix all KiCad symbol lib_ids — zero update errors now
    Corrected lib_id references for INA226, SN65HVD230, TPS5430DDA,
    CP2102N, and LM5116 across all 4 sub-sheets. Added LM5116MHX_NOPB
    custom library from SnapEDA. All symbols resolve on Update from Library.
    [Connectors_LED_USB.kicad_sch, Drivers_CAN_IMU_Power.kicad_sch, ICM-42688-P.step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]
2026-04-10 Add prototype schematic + tighten product layout to A3
    Product: All 4 sub-sheets resized A2/A1→A3, components repositioned
    into tight logical groups, duplicate K1/Q1 removed.
    Prototype: New KiCad project with 3 hierarchical sheets
    (Power, Teensy/Motor Control, Peripherals/Sensors), BOM, and
    netlist reflecting as-built wiring: MD13C R3 + BTS7960 asymmetric
    drivers, DC disconnect, 6-way fuse block, XINGYHENG servo buck.
    [Connectors_LED_USB.kicad_sch, Drivers_CAN_IMU_Power.kicad_sch, Peripherals_Sensors.kicad_sch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]
2026-04-19 Rewrite README for portfolio — full project overview, subsystems, contributions
2026-04-19 Clean up repo — remove internal files, add .gitignore, remove KiCad backups
2026-04-19 Add ROS2 workspace, navigation code, schematics, MATLAB sims, and docs
    - reclaim_ws/src: full ROS2 packages (perception, navigation, control, bringup, interfaces)
    - docs/mic_snapshot_mar24: teensy_bridge.py, waste_tracker.py (visual servoing)
    - docs/schematic_images: exported PDFs and wiring guide
    - matlab_sims: motor modelling, Bode plots, control tuning
    - docs: Teensy reference, perception strategy, navigation deep dive, drive changelog
    - URDF arm model, sync/setup scripts, test guides
    [URDF Arm Model.urdf, base_link.STL, base_rotation.stl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]
2026-04-19 Remove schematic generation scripts, fix Claude reference in firmware comment
    [main.cpp]
2026-04-19 Fix motor driver name: MD10C → MD13C R3
2026-04-19 Add MoveIt2 and URDF details to robotic arm section
2026-04-19 Connect arm to Teensy in system overview diagram
